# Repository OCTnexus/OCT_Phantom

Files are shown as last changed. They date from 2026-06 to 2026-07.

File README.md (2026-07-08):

# TiO2 OCT Phantom Protocol

This repository contains documentation and fabrication support files for titanium dioxide (TiO2) optical scattering phantoms used as physical reference objects for optical coherence tomography (OCT) imaging and attenuation measurement validation.

The main protocol describes cartridge-format TiO2-doped PDMS phantoms assembled with a cover glass, sealed sample chamber, buffer chamber, inlet port, epoxy sealing channel, and protective 3D-printed enclosure. The phantoms are intended for OCT system performance assessment, repeatability testing, and comparison of quantitative attenuation measurement methods.

## Repository Contents

| Path | Description |
| --- | --- |
| [`TiO2_OCT_Phantom_Protocol_V3.pdf`](TiO2_OCT_Phantom_Protocol_V3.pdf) | Current protocol PDF, including fabrication workflow, optical characterization methods, handling guidance, safety notes, storage, and shipping instructions. |
| [`3D Printed Components/`](3D%20Printed%20Components/) | CAD and STL files for the phantom cartridge, trap, enclosure/case parts, and related printed components. |
| [`SDS_Files/`](SDS_Files/) | Safety data sheets currently included with the repository. |

## Protocol Summary

The protocol covers:

- Fabrication of TiO2-PDMS optical scattering phantoms.
- Preparation of the 3D-printed cartridge and cover-glass seal.
- Mixing, dispersion, filling, vacuum degassing, and curing of the scattering PDMS sample.
- Final assembly of the protective cartridge enclosure.
- Optical property measurements using integrating-sphere measurements, inverse adding-doubling analysis, and low-coherence interferometry.
- Labeling, handling, storage, shipping, and safety requirements.

The protocol reports example phantom sets with TiO2 concentrations from 1 mg/g to 20 mg/g and measured reduced scattering, absorption, scattering, and anisotropy values. See the PDF for the measurement tables, serial-number format, figures, and references.

## 3D Printed Components

The [`3D Printed Components/`](3D%20Printed%20Components/) folder includes:

- [`Phantom_Hill.stl`](3D%20Printed%20Components/Phantom_Hill.stl) - STL model for the imaging hill.
- [`Phantom_trap.stl`](3D%20Printed%20Components/Phantom_trap.stl) - STL model for the phantom trap component.
- [`Phantom_trap_case_part1.stl`](3D%20Printed%20Components/Phantom_trap_case_part1.stl) and [`Phantom_trap_case_part2.stl`](3D%20Printed%20Components/Phantom_trap_case_part2.stl) - STL models for the protective case/enclosure parts.

Review the printed parts against the dimensions and assembly steps in the protocol before fabrication.

## Safety Data Sheets

The [`SDS_Files/`](SDS_Files/) folder currently includes:

- [`Gorilla-Epoxy-Syringe-Resin.pdf`](SDS_Files/Gorilla-Epoxy-Syringe-Resin.pdf)
- [`Sylgard_184_base.pdf`](SDS_Files/Sylgard_184_base.pdf)
- [`Sylgard_184_CuringAgent.pdf`](SDS_Files/Sylgard_184_CuringAgent.pdf)

Before fabrication, confirm that all current SDS documents required by the protocol are available to personnel, including the SDS for the specific TiO2 powder used in the lab.

## Basic Workflow

1. Read the current protocol PDF completely before fabrication.
2. Print and inspect the cartridge and enclosure components.
3. Prepare the cartridge, cover glass, and epoxy seal as described in the protocol.
4. Prepare the TiO2-PDMS mixture using the target concentration and the specified base-to-curing-agent ratio.
5. Fill, degas, and cure the phantom cartridge.
6. Assemble the protective enclosure.
7. Inspect, label, measure, and store the phantom according to the protocol.

## Shelf Time Track

<p align="center">
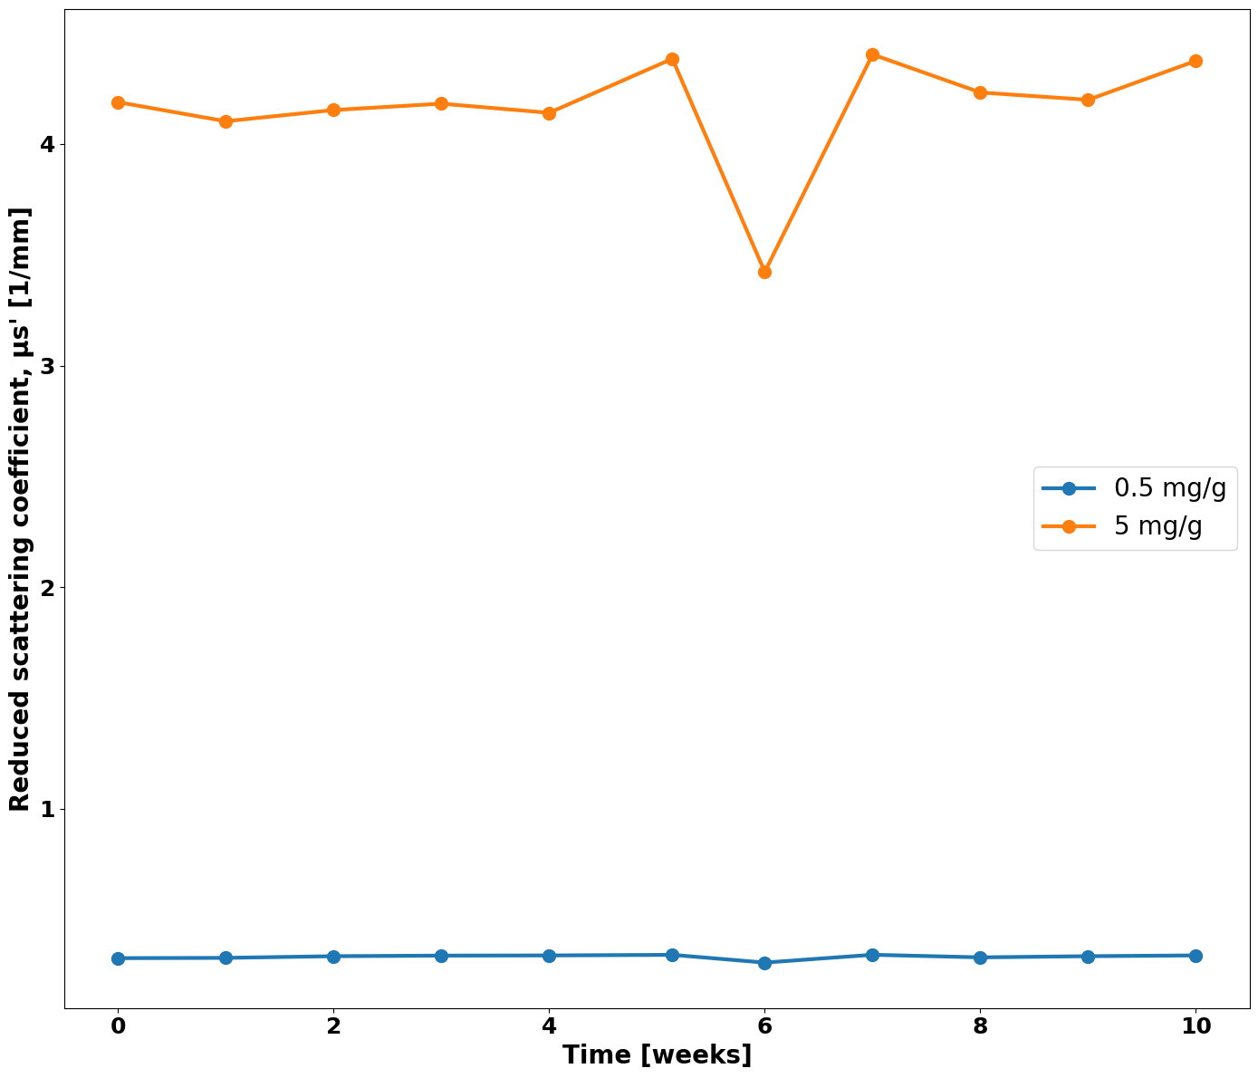
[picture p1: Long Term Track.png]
Shelf Time Track
  
</p>

## Use Limitations

These phantoms are research and validation tools for optical imaging systems. They are not clinical diagnostic devices, are not intended for sterile use, and are not intended for direct patient contact.

## Acknowledgment

This work is supported by NIBIB R21EB03393 for the National Medical Phantom Library (NMPL).

## Citation



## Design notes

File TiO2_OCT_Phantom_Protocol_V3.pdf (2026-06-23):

## TiO2 Scattering Phantom for Optical Coherence Tomography

Version: 03

Date: 23 June, 2026

By: Hui Wang @Miami University

## Contents

### 1. Purpose and Measurement Metrics

The purpose of these TiO₂-based optical scattering phantoms is to provide stable, well-characterized physical reference standards for optical coherence tomography (OCT). OCT is not limited to structural imaging. In addition to visualizing tissue morphology, quantitative analysis of the OCT signal enables estimation of optical properties, including the optical attenuation coefficient, which is related to tissue microstructure, organization, and composition and may provide additional diagnostic information¹,2. Quantitative attenuation analysis has therefore been investigated as a potential approach for tissue differentiation and for improving the diagnostic capability of OCT.

However, accurate attenuation measurement remains challenging. Conventional OCT-based attenuation estimates can be biased by simplifying model assumptions, the confocal point-spread function, sensitivity roll-off, and the contribution of multiply scattered photons, all of which can reduce the accuracy of optical-property estimation³
. These effects are particularly significant in highly scattering media, where multiple scattering and depth-dependent signal distortions become more pronounced. For this reason, reliable physical reference standards are needed. The TiO₂-based phantoms described here are designed to support validation of optical attenuation coefficient (OAC) quantification methods by providing controlled scattering references with independently measured optical properties. OCT-derived attenuation values can therefore be evaluated against reference measurements obtained using established optical characterization techniques.

The optical properties of biological tissues are commonly described by the reduced scattering coefficient, µ′s; absorption coefficient, µa; scattering coefficient, µs; and anisotropy factor, g⁴
. These parameters depend on tissue type, composition, and wavelength. In OCT, the optical attenuation coefficient is determined by both absorption and scattering and is commonly modeled as the sum of these contributions. In this protocol, integrating-sphere measurements combined with inverse adding-doubling analysis are used to quantify µ′s and µa⁵,6 . A simple and robust low-coherence interferometry method is then applied to quantify µs. The anisotropy factor, g, is subsequently calculated from the relationship:

### μ′s = (1 − g)μs

The intended applications of these phantoms are specific and well defined. They are intended for OCT system performance assessment, repeatability testing, and comparison of attenuation-measurement methods. They are not intended to serve as complete biological tissue models, nor are they clinical diagnostic devices. Rather, they are controlled optical scattering references designed to support the validation and standardization of OCT-based quantitative measurement methods.

### 2. Physical Reference Object

The physical reference object in this phantom package is cartridge-format TiO₂-based optical scattering phantoms. The phantom is intended to serve as the physical reference object for OCT imaging. Each completed phantom is assigned a unique serial number with a model number. The serial number and the model number are printed on the side of the cartridge and is used to identify the individual phantom throughout fabrication, quality control, storage, use, and future reference.

Model NO.: OCTP820 -TIO2
SN: S###-G##- B##-YYMMDD

OCTP820 = COT phantom calibrated at 820nm T = TiO2 scattering phantom
S### = scattering coefficient µs in mm-1 ×10 G## = anisotropy×100
B## = batch number
YYDD = batch date

Examples:
µs = 2.0 mm⁻¹ g =0.90 batch = 1 date = 2026-05-15 scatters = TiO2 | OCT820-TIO2 SN: S020-G90-B01-260515
µs = 0.5 mm⁻¹ g =0.85 batch = 2 date = 2026-06-15 scatters = TiO2 | OCT820-TIO2 SN: S005-G85-B02-260615

The phantoms are stored and transported in a protective container to reduce mechanical damage, contamination, and damage to the optical window. No separate mounting fixture is required for routine storage or handling. If a dedicated holder or alignment fixture is used during OCT imaging, that fixture is stored with the phantom and labeled with the corresponding phantom serial number.

### 3. Fabrication Protocol

This part describes fabrication of a TiO₂-doped PDMS optical scattering phantom assembled in a 3D-printed cartridge with a cover glass, sealed sample chamber, buffer chamber, inlet port, epoxy sealing channel, and protective cartridge enclosure. The procedure covers cartridge preparation, scattering-PDMS preparation, filling, vacuum degassing, curing, final enclosure assembly, and pre-release fabrication inspection.

### 4. Fabrication Workflow Overview

The fabrication workflow shall be followed in the order shown in Figure 1.

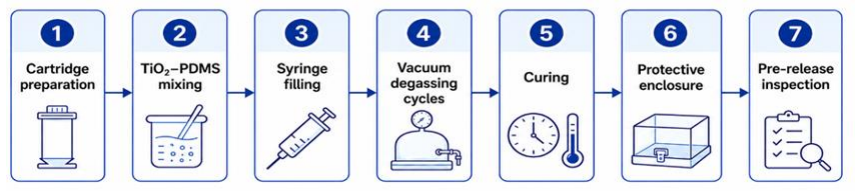
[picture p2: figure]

### 4.1. Cartridge Components

Figure 2 identifies the key cartridge components and supporting fabrication parts.

Figure 1. The fabrication flow of the phantom

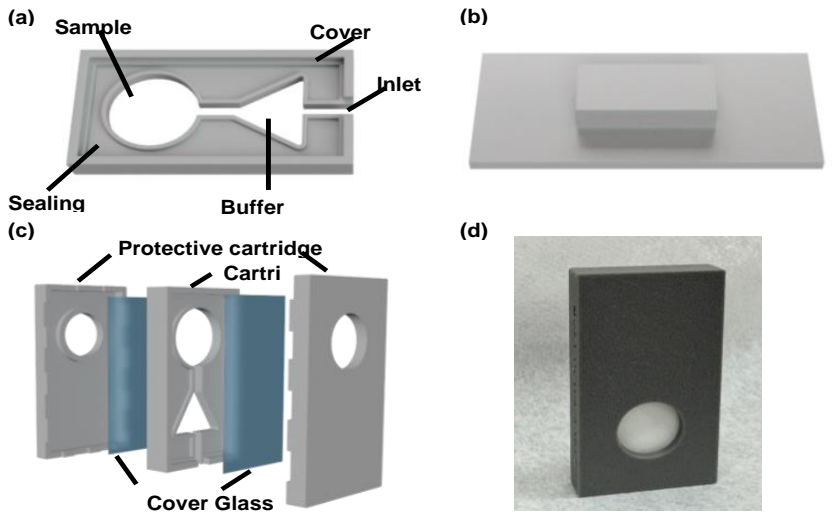
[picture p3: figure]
(b) Sample; Cover; Inlet; Sealing; Buffer; Protective cartridge; Cover Glass; Cartri

Figure 2. Cartridge-based TiO₂ optical scattering phantom components. A) 3D-printed cartridge schematic with sample chamber, cover glass seat, inlet port, sealing channel, and buffer chamber. B) 3D-printed glass weight used during cover-glass sealing. C) Exploded view of cartridge and protective enclosure. D) Placeholder image of final phantom cartridge.

### 4.2. Materials and equipment

Prepare the following materials and equipment before fabrication begins.

- 3D printer (P1S, Bambu)
- 3D-printed cartridge base
- Cover glass (24 mm x 50 mm) (CS-24X50-100, Amscope)
- Sylgard 184 PDMS elastomer kit (base + curing agent) (68083-19-2/68988-89-6, DOW)
- Gorilla Epoxy (4200102, The Gorilla Glue Company)
- 99.9% 100 nm titanium dioxide (TiO2) nano powder (US3535, US Research Nanomaterials)
- Syringe with flat-tip needle
- Disposable weighing boats
- Mixing silicone containers
- Magnetic stir plate (PC-420D, Corning)
- Magnetic stir bar
- Ultrasonic bath (230HT, Zokop)
- Vacuum chamber and vacuum pump (RS-1, 1 Stage)
- 3D-printed glass weight
- Protective cartridge enclosure
- Acetone-moistened wipe for excess epoxy removal during final assembly

### 4.3. Cartridge preparation

1. Mix equal volumes of epoxy resin and hardener in a clean disposable container, such as a weighing boat.
2. Pour 0.825 mL epoxy to the sealing channel of the 3D-printed cartridge evenly.
3. Place the cover glass into the cover glass seat of the cartridge.
4. Place a 3D-printed weight on top of the cover glass to apply uniform pressure and ensure that the glass sits flat, then remove the weight.
5. Repeat the epoxy filling step to seal the sealing channels on both sides of the cartridge.
6. Allow the epoxy to cure at room temperature for 24 hours.

### 4.4. Scattering PDMS sample preparation

7. Weigh the desired amount of PDMS base into a clean mixing silicone container and record the mass.
8. Weigh the required amount of TiO2 powder in a weighing boat according to the target scattering concentration and record the mass.
9. Add the TiO2 powder to the PDMS base.
10. Mix the suspension using a magnetic stir plate and stir bar for 20 minutes at 200 rpm to disperse the particles.
11. Place the mixture in an ultrasonic water bath (40KHz/120W) for 20 minutes to improve TiO2 dispersion.
12. Add PDMS curing agent to the mixture using a 10:1 base-to-curing-agent weight ratio.
13. Mix again on the magnetic stir plate for 20 minutes at 200 rpm.

### 4.5. Phantom filling and degassing

14. Draw the PDMS-TiO2 mixture into a syringe.
15. Inject the mixture into the cartridge through the PDMS inlet until the buffer chamber is filled to approximately two-thirds capacity.
16. Place the cartridge in a vacuum chamber.
17. Slowly reduce the chamber pressure using the vacuum pump.
18. When the PDMS begins to foam and bubbles expand, monitor the chamber carefully.
19. Temporarily close the vacuum valve if foam approaches the cartridge opening.
20. Wait until the bubbles collapse.
21. Slowly vent the chamber to atmospheric pressure.

22. Allow the cartridge to rest for 5 minutes.
23. Repeat the vacuum cycle until no bubbles form at approximately 29 inHg vacuum.

### 4.6. Phantom curing

24. Place the cartridge upright at room temperature for 24 hours to fully cure the PDMS.

### 4.7. Final assembly

25. Install the protective enclosure over the cartridge.
26. Apply epoxy adhesive along the enclosure seams to seal the cartridge.
27. Remove any excess epoxy that squeezes out from the seams using a wipe moistened with acetone.
28. Once the excess epoxy is cleaned and the enclosure is secured, the device can be used immediately without waiting for full epoxy curing.

### 5. Quantification

### 5.1. Instrumentation

- Integral spheres: General Purpose Integrating Sphere from Labsphere
- Spectrometer: LR1from ASEQ Instruments
- Laser: SLD371 from Superlum Ireland
- Low coherent interferometer: In-house built 850nm spectral domain interferometer

### 5.2. Software

- Inverse Adding-Doubling (IAD) (https://github.com/scottprahl/iad)
- OCTSharp (https://github.com/OCTSharpImaging/OCTSharp)

### 5.3. Method: Reduced scattering and absorption coefficient measurement

The reduced scattering coefficient (µ’s) and attenuation coefficient (µa) of each TiO₂-PDMS phantom are determined using integrating spheres followed by Inverse Adding-Doubling (IAD) analysis using the optical setup shown in Figure 3. The flip mirror is used to direct the beam to either the reflectance integrating sphere or the transmittance integrating sphere. For the reflectance measurement, the sample is mounted at the sample port of the integrating sphere, and the diffusely reflected light is collected by the detector fiber. Before sample measurement, dark measurements and reference measurements are collected for background subtraction and instrument normalization. The corrected diffuse reflectance and total transmittance values are then entered into the IAD calculation together with the sample thickness of 3 mm, measurement wavelength of 824.4 nm, refractive index of the sample of 1.41(PDMS), refractive index of

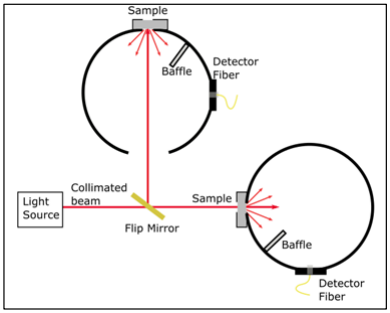
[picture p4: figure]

the surrounding medium of 1.51(Glass slide) , and integrating-sphere geometry. The IAD algorithm estimates the sample optical properties as µ’s (mm⁻¹

) and µa (mm⁻¹
) by iteratively solving the radiative transport problem.

### 5.4. Method: Attenuation measurement

The attenuation coefficient (µt) shall be measured as an independent parameter to support the IAD calculation. Conventional collimated transmission, shown in Fig. 4(a), estimates ballistic transmittance by measuring light transmitted through the sample. This method is sensitive to sample thickness, detector dynamic range, and

Figure 3. The Integral sphere system used to quantify the reduced scattering coefficient µ’s and absoption coefficient µa of the phantoms.

collection geometry because forward-scattered light may reach the detector and cause underestimation of µt. Therefore, it shall not be used as the primary attenuation measurement for these scattering phantoms⁵

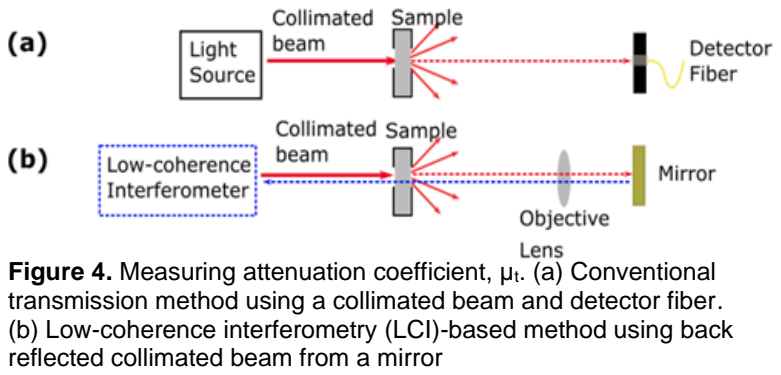
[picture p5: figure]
reflected collimated beam from a mirror

In this protocol, µt has been measured using the low-coherence interferometer (LCI) configuration shown in Fig. 4(b). The LCI beam passes through the sample, reflects from a mirror, and passes through the sample a second time before returning to the interferometer. The mirror interference peak is used as the measurement signal. Because LCI has coherence gating, the detected signal is dominated by ballistic or least-scattered photons, reducing the contribution of multiply scattered light. The sample is placed in the collimated beam before the objective lens to eliminate confocal-gate effects during attenuation measurement.

### 5.5. Measured results of the phantoms

To determine the anisotropy factor, g, of the TiO₂ phantoms, we fabricated three phantoms with different TiO₂ concentrations, as listed in Table 1. Because absorption by the phantoms at approximately 800 nm is very low, two orders less than scattering coefficients, it is reasonable to assume that μs ≈ μt, where μt was measured using the LCI-based method. The resulting μs values were then used as inputs to the IAD algorithm, together with the data acquired using the double integrating spheres, to calculate g.

Table 1. Optical properties of TiO₂ phantoms used to calculate the anisotropy factor g.

Concentration (mg/g) | µ’s (mm-1) | µs (mm-1) | g
0.5 | 0.3 ± 0.0027 | 0.88 ± 0.0032 | 0.66 ± 0.0033
0.75 | 0.44 ± 0.006 | 1.31 ± 0.027 | 0.66 ± 0.0083
1 | 1.88 ± 0.019 | 5.48 ± 0.053 | 0.66 ± 0.0048
Using the determined anisotropy factor, g, we fabricated five phantoms with different TiO₂ concentrations and quantified their optical properties. All measured data are listed in Table 2, together with the corresponding serial numbers. The linear relationship between TiO₂ concentration and the scattering coefficient, μs, is plotted in Fig. 5. The OCT images of these phantoms are shown in Fig.6. The cover glass thickness is 190 µm, and the material is BK7 glass with a refractive index of approximately 1.51 at 800 nm. These cover-glass boundaries can be used as the reference for image-dimension verification and prevent the specular reflection from the phantom surface.

Table 2. Optical properties of TiO₂ phantoms computed from double integrating sphere measurements.

Concentration (mg/g) | | Serial Number | µ’s (mm⁻¹ ) | µa (mm⁻¹ ) | µs (mm⁻¹ ) | g
| S052-G066-B01-
1
260312 | 1.76 ± 0.018 | 0.014 ± 0.0006 | 5.18 ± 0.053 | 0.66

5

S137-G066-B01-
260313 | 4.64 ± 0.039 | 0.0089 ± 0.00028 | 13.65 ± 0.11 | 0.66
10 | S217-G066-B01-
260314 | 7.39 ± 0.14 | 0.0082 ± 0.00051 | 21.73 ± 0.42 | 0.66
15 | S315-G066-B01-
260315 | 10.73 ± 0.15 | 0.0075 ± 0.00035 | 31.55 ± 0.44 | 0.66
20 | S414-G066-B01-
260316 | 14.09 ± 0.14 | 0.0041 ± 0.00043 | 41.43 ± 0.41 | 0.66

Figure 4. Measuring attenuation coefficient, µt. (a) Conventional transmission method using a collimated beam and detector fiber.
(b) Low-coherence interferometry (LCI)-based method using back

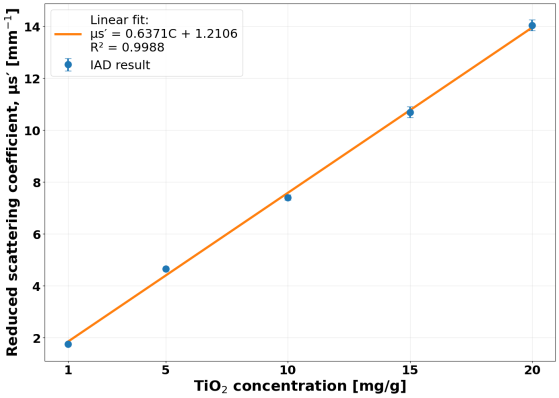
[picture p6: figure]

Figure 5. Reduced scattering coefficient as a function of TiO₂ concentration

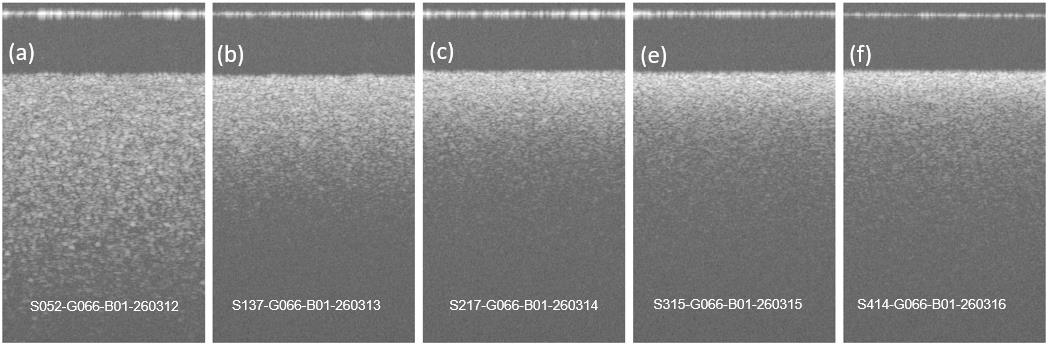
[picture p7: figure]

### 6. Operation and Handling

### 6.1. Operation

Use the phantom only for research and validation of optical imaging/OCT systems unless a separate regulatory or clinical-use document is approved. Handle the cartridge carefully to avoid contamination of the cover glass or optical window. Before use, inspect the phantom for cracks, leakage, delamination, large bubbles, surface contamination, or label damage. Do not use the phantom if leakage, broken glass, optical-window contamination, or unreadable labeling is observed. During imaging, place the phantom under the laser beam using the approved OCT sample holder or stage. The phantom may be placed at a slight angle relative to the illumination optical axis to reduce strong specular reflection from the cover glass.

The phantom should be placed directly beneath the OCT laser beam, with the beam passing through the optical window. To avoid strong specular reflection from the phantom surface, several angled fixtures with different tilt angles were provided for positioning the phantoms.

### 6.2. Permitted use

- OCT imaging performance evaluation, repeatability testing, and comparative imaging studies using controlled scattering media.
- Bench testing under controlled laboratory conditions.

### 6.3. Use limitations

- Not intended for direct patient contact.
- Not intended for sterile use.
- Not a clinical diagnostic device.

Figure 6. OCT images of the phantoms list in Table 5

- Do not expose to extreme heat, freezing conditions, direct sunlight, abrasive cleaning, or unapproved solvents.

### 7. Environmental Sensitivity and Monitoring

### 7.1. Fabrication and curing environment

- Recommended fabrication room temperature: 20-25 deg C
- Recommended relative humidity: below 60 percent.
- Fabricate and cure in a clean, dust-minimized area.
- Avoid vibration during curing and protect the sample from dust
- Phantoms shall be inspected before use for cracks, delamination, large bubbles, surface contamination, or other damage.

### 7.2. Shelf time

Two replicate phantom cartridges are stored under room-temperature conditions and measured weekly to monitor stability over time as shown in r. The weekly monitoring data will be maintained as part of the phantom documentation and updated in the protocol as data become available through GitHub. Until sufficient stability data are collected, no final shelf-life claim is assigned.

### 8. Safety Components

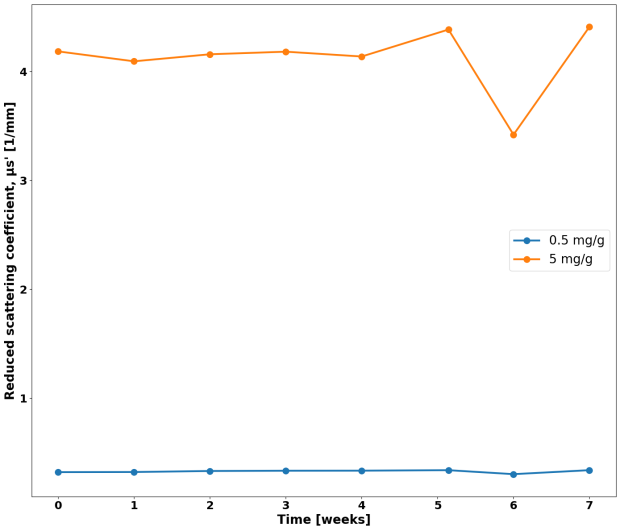
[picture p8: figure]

Safety documentation must be maintained with the phantom package. Current SDS documents should be available to personnel before fabrication begins.

### 8.1. Required SDS files attached with documentation

- Titanium dioxide powder
- Sylgard 184 PDMS base
- Sylgard 184 PDMS curing agent
- Two-part epoxy resin and hardener

### 8.2. Personal protective equipment and safe handling

- Wear a lab coat, nitrile gloves, face mask, and safety glasses during all fabrication steps.
- Handle dry TiO2 powder in a fume hood or other approved local exhaust system to minimize inhalation risk.
- Avoid generating TiO2 dust clouds; do not blow or dry sweep TiO2 powder.
- Avoid skin and eye contact with PDMS curing agent, uncured epoxy, acetone, and uncured PDMS mixtures.

Figure 7. Long-term stability monitoring of the reduced scattering coefficient (μs′) for TiO₂ phantoms measured by double integrating sphere. (a) 0.5 mg/g TiO₂ phantom (b) 5 mg/g TiO₂ phantom.

### 8.3. Spill and accident response

- TiO2 powder spill: dampen powder or use an approved HEPA-filtered vacuum; do not dry sweep.
- Uncured PDMS or epoxy spill: contain and absorb with compatible inert material, then dispose as chemical waste according to institutional policy.
- Skin contact: wash with soap and water and remove contaminated clothing.
- Eye contact: Rinse cautiously with water for several minutes and seek medical attention if irritation persists.
- Inhalation of TiO2 dust: move to fresh air and seek medical attention if symptoms occur.

### 8.4. Waste disposal

- Cured PDMS and cured epoxy may be handled as solid waste only if permitted by institutional policy.
- Uncured PDMS, curing agent, uncured epoxy, acetone wipes, and contaminated absorbents should be collected as chemical waste unless EHS approves another route.
- TiO2-contaminated gloves, wipes, or weighing boats should be collected in a labeled solid waste container according to institutional EHS instructions.
- Do not pour TiO2, uncured PDMS, or epoxy down the drain.

### 9. Shipping and Storage Protocols

### 9.1. Storage

- Storage in room temperature: 20-25 °C
- Store in the enclosure box and avoid direct sunlight and prolonged UV exposure.
- Avoid freezing or refrigeration unless stability testing demonstrates no change in optical or mechanical properties.

### 9.2. Shipping protocol

- Place the phantom package in a sealed enclosure.
- Add cushioning such as foam inserts or bubble wrap to prevent movement.
- Place the primary container in a rigid secondary box.

References
1 Vermeer KA, Mo J, Weda JJA, Lemij HG, Boer JF de. Depth-resolved model-based reconstruction of attenuation coefficients in optical coherence tomography. Biomed Opt Express 2014; 5: 322–337.

2 Chang S, Bowden AK. Review of methods and applications of attenuation coefficient measurements with optical coherence tomography. J Biomed Opt 2019; 24: 090901.

3 Almasian M, Bosschaart N, Leeuwen TG van, Faber DJ. Validation of quantitative attenuation and backscattering coefficient measurements by optical coherence tomography in the concentration-dependent and multiple scattering regime. J Biomed Opt 2015; 20: 121314.

4 Cheong WF, Prahl SA, Welch AJ. A review of the optical properties of biological tissues. IEEE J Quantum Electron 1990; 26: 2166–2185.

5 Prahl S. Everything I think you should know about Inverse Adding-Doubling. Or Med Laser Cent St Vincent Hosp 2011; : 1–74.

6 Prahl SA, Gemert MJC van, Welch AJ. Determining the optical properties of turbid media by using the adding– doubling method. Appl Opt 1993; 32: 559–568.

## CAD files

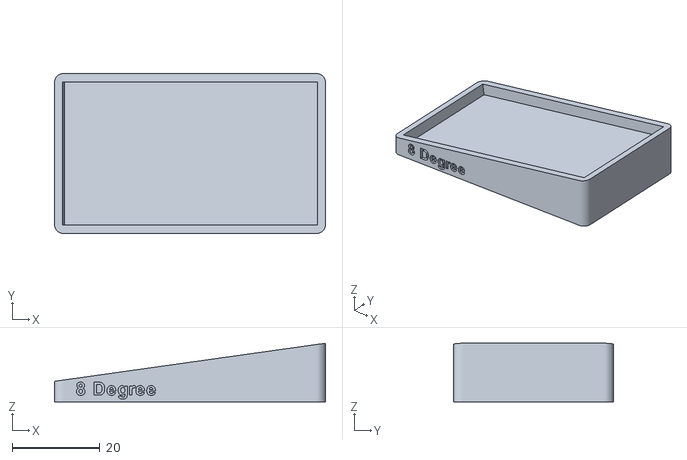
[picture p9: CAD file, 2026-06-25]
3D Printed Components/Phantom_Hill.stl
61.9 x 36.5 x 13.4

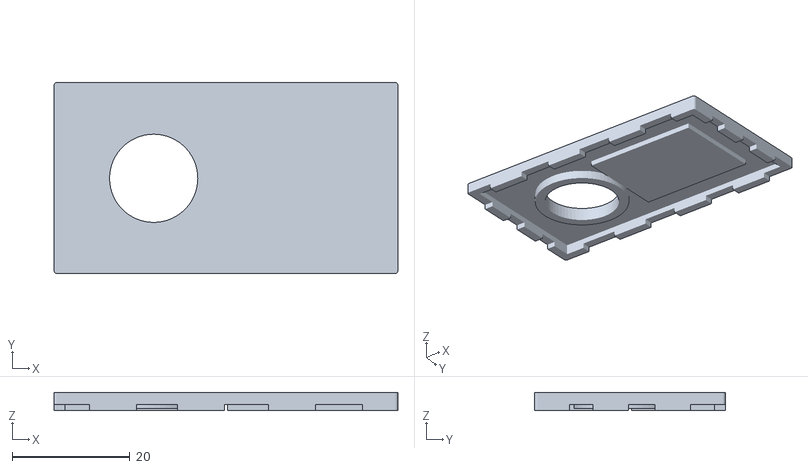
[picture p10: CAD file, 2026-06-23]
3D Printed Components/Phantom_trap_case_part2.stl
58.5 x 32.5 x 3.10

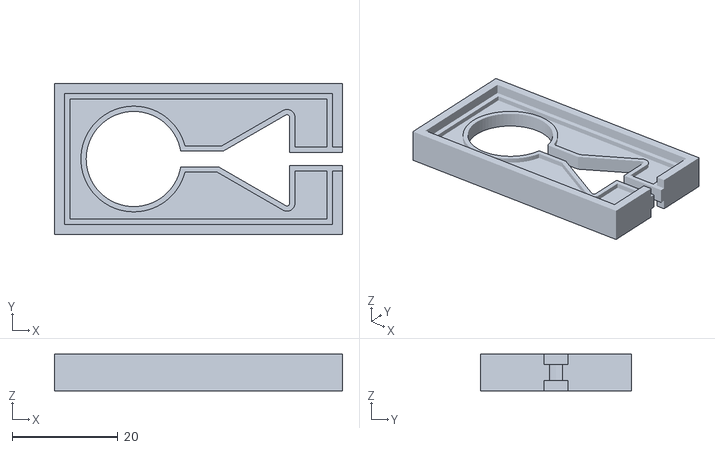
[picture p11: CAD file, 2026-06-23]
3D Printed Components/Phantom_trap.stl
54.5 x 28.5 x 7.00

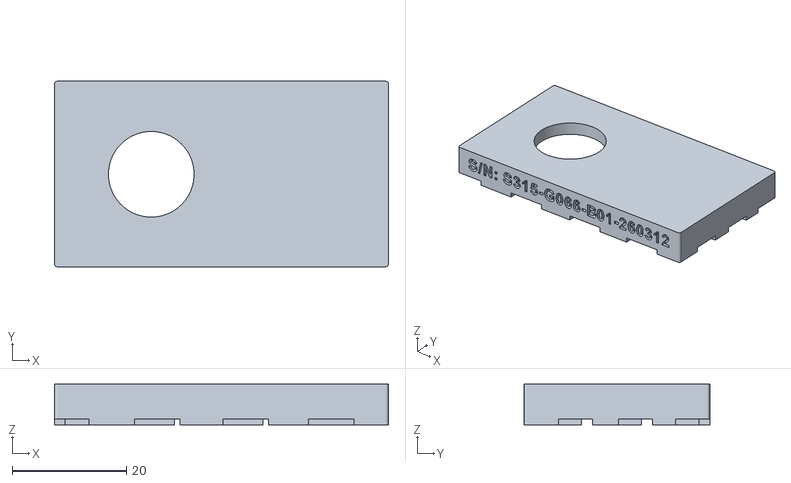
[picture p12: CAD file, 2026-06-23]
3D Printed Components/Phantom_trap_case_part1.stl
58.5 x 32.5 x 7.10
